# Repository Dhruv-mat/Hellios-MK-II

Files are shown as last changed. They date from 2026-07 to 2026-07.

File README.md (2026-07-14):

# Project Description

Helios Mk-II is an autonomous rover engineered to actively analyze and understand its environment rather than just driving between coordinates. The core navigation loop is straightforward: the rover is given a target GPS location and determines its own path to the destination. When encountering an obstacle, it avoids forcing a path; instead, it decelerates, scans the surroundings using its integrated LiDAR and camera payload, maps out a local environment model, and dynamically computes a safe detour or calculates an entirely new route if the path is completely blocked.

To bridge the gap between complex robotics and user experience, Helios features an AI-powered mission narration engine. Rather than outputting standard, dry terminal logs, the system synthesizes the navigation telemetry into a real-time narrative. Every sudden obstacle, recalculated path, or mission milestone is translated into a live commentary stream, transforming standard autonomous data tracking into an engaging, story-driven experience.

Beyond navigation, the rover includes a dedicated research mode designed for localized data collection. While traversing an area, the platform captures high-resolution imagery and logs environmental telemetry, geotagging all data points with precise GPS coordinates. This payload data can be extracted post-mission for specialized applications like agricultural monitoring, plant disease detection, or environmental mapping, making the vehicle a highly capable mobile sensor platform.

Future development plans include a hardware-linked follow-me mode. In this configuration, the rover tracks a dynamic target—such as a mobile device interface—instead of a fixed geographic coordinate. While following, the AI narration engine remains fully active, contextualizing the local environment and interactions in real time to turn a routine field test into an interactive demonstration.

At its core, Helios Mk-II integrates robotics, computer vision, autonomous navigation, embedded systems, and generative AI into a single cohesive platform. The objective extends beyond basic mobility; the project aims to deliver an intelligent system capable of environmental awareness, autonomous decision-making, high-utility data collection, and intuitive human-robot interaction.

# Build Guide
## Step 1: The Main Chassis & Pillars

Start by printing out the main base. Next, grab the B and C pillars. You’ll need to pop M3 nuts right into the slots on the pillars themselves, then secure them by driving M3 screws up from the bottom of the base. Go ahead and repeat this process for both sides. Once the pillars are locked down, take the B and C pillar stabilizers and slide them in from the top—they should just drop right into place. After that, use a bit of glue to secure the canopy onto the Main Base.







## Step 2: The Differential, Pillars, and Roofs

Next up is the differential plate. Insert M3 nuts into the diff connector, and secure it by screwing it in from the bottom of c pillar stabaliser plate. Use this exact same method as the pillar mounting way to attach to the rear wing. Once those are in place, you can just magnetically snap roof A and roof B onto the top.





## Step 3: The Suspension & Carbon Fiber Rods

Moving on to the B pillars, press-fit two ball bearings into each side. Once those are seated, take the main connector and fasten it onto the small pendulum piece using four screws. Now grab your carbon fiber rods, cut them down to 15 cm and 17 cm lengths, and secure them directly into the main connector.





## Step 4: The Bogie and Front Steering Setup

Mount the bogie connector to the rear, and fit the servo holder onto the front. Make sure to press two ball bearings into the bogie connector, then bolt the entire bogie assembly together using an M6 bolt.





To link up the front connector to the front motor housing, you'll first need to mount the servo motor into the front servo housing connector. Once the servo is seated, the front assembly hooks right on with a few screws. For the middle and rear sections, simply slide the motor housings into place and lock them down with screws, then press the motors inside.



## Step 5: Linking the Pendulums & Differential

For the top section, take the pendulum connector and secure it onto the pendulum using an M5 bolt to bridge both sides.

To get the differential linkage hooked up, take the diff and a ball bearing. Pop the bearing inside the diff connector, then bolt the connector onto the differential using an M5 bolt. Make sure to tighten this diff connector piece just a little bit so it has room to pivot. Next, take the LR66 linkages and screw them onto both ends of the diff. Finally, grab an M6 bolt and attach the pendulum connector directly to the LR66.



## Step 6: Final Assembly & Electronics

With everything linked up, you can go ahead and pop the wheels onto the motor shafts. To get the electronics and your custom PCB mounted inside the chassis, just follow the electronics placement guide and refer to the main wiring diagram to get all your connections sorted.





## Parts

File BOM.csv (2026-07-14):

No. | Part Name | Quantity | Owned | Seller | Price
1 | Pro-Range OG555 High Torque DC Motor 12V 100RPM 173.6N-cm Encoder Available | 6 | No | Robu | 50
2 | SmartElex 15D PWM & RC Dual Channel Motor Driver | 3 | No | Robocraze | 44
3 | Arduino Mega | 1 | No | Robocraze | 11
4 | Lidar | 1 | Yes | Robu | -
5 | Rasberry PI AI Camera | 1 | Yes | Robocraze | -
6 | Rasberry PI 5 | 1 | Yes | Robu | -
7 | PDB | 1 | Yes | Amazon | -
8 | GPS | 1 | Yes | Amazon | -
9 | GSM | 1 | Yes | Robu | -
10 | RC KIT | 1 | Yes | Robu | -
11 | M3 Screw Pack | 1 | Yes | Only Screws | -
12 | 626 ZZ - Deep Groove Ball Bearing (ID:6mm OD:19mm T:6mm) | 6 | No | Only Screws | 1.1
13 | 625 ZZ - Deep Groove Ball Bearing (ID:5mm OD:16mm T:5mm) | 3 | No | Only Screws | 0.6
14 | M3 X 5mm Brass Threaded Inserts (Dia. 3mm, Length 5mm) | 25 | No | Only Screws | 0.6
15 | Neodymium Bar Magnet N35 (Length: 25mm, Breadth: 10mm, Thickness: 2mm) | 8 | No | Only Screws | 2.3
16 | Pro-Range DS3218 20kgcm Metal Gear Digital Servo Motor - 180 degree | 2 | No | Robu | 26
17 | Carbon Fiber Tube (Hollow)16mm(OD)*14mm(ID)*185mm(L) (Twill Matte Black) | 6 | No | Robu | 9
18 | Lipo Battery | 1 | Yes | Robu | -
19 | UBEC | 1 | No | Robu | 2
20 | M6 X 65mm Hex Bolt SS304 (Dia. 6mm, Length. 65mm) | 2 | No | Only Screws | 0.7
21 | M3 X 20mm Male to Female Nylon Hex Threaded Standoff Spacer | 12 | No | Only Screws | 0.5
22 | M6 X 45mm Hex Bolt SS304 (Dia. 6mm, Length. 45mm) | 2 | No | Only Screws | 0.3
23 | M6 X 50mm Hex Bolt SS304 (Dia. 6mm, Length. 50mm) | 2 | No | Only Screws | 0.3
24 | Arduino-to-Pi cable(type b usb) | 1 | Yes | Amazon | -
25 | Robot car Wheel (125mm) Black-Blue with (6mm Coupling) | 6 | No | Robocraze | 36
26 | M5 X 16mm Hex Bolt SS304 (Dia. 5mm, Length. 16mm) | 2 | No | Only Screws | 0.07
27 | M5 Hex Nut SS304 (Dia. 5mm) | 4 | No | Only Screws | 0.02
28 | M6 Plain Washer SS304 (ID. 6.7mm OD:11.8mm T:1.6mm) | 12 | No | Only Screws | 0.19
29 | M6 Hex Nut Mild Steel Black (Dia. 6mm) | 8 | No | Only Screws | 0.09
30 | M6 X 80mm Hex Bolt SS304 (Dia. 6mm, Length. 80mm) | 2 | No | Only Screws | 0.26
31 | M5 Plain Washer SS304 (ID. 5.4mm OD:9.8mm T:1mm) | 6 | No | Only Screws | 0.19
32 | M5 X 25mm Hex Bolt SS304 (Dia. 4mm, Length. 25mm) | 2 | No | Only Screws | 0.09
33 | 20AWG 3 Core Multicore Silicone Cable Red Black Green Flexible Wire | 3 | no | Robu | 3.63
34 | 14AWG Silicone Braided wire-Black | 1 | No | Robu | 1
35 | 14AWG Silicone Braided wire-Red | 1 | No | Robu | 1
36 | PCB Manufacturing | 1 | No | JLC | 2
37 | 1x40 Pin 2.54MM Berg Strip Male connector | 2 | No | Robu | 1
38 | LED red | 1 | yes | Robu | -
39 | LED white | 1 | yes | Robu | -
40 | LED blue | 1 | yes | Robu | -
41 | resistor 470Ω | 3 | yes | Robu | -
42 | Heat Shrink | 1 | yes | Robu | -
43 | Zip Ties | 1 | yes | Robu | -
44 | XT60 male | 1 | no | Robu | 1
45 | Battery voltage checker | 1 | yes | Robu | -
46 | 2.54mm 1x40 Pin Female Single Row Header Strip | 3 | No | Robu | 1
 |  |  |  | T
 |  |  | TOTAL |  | 144$

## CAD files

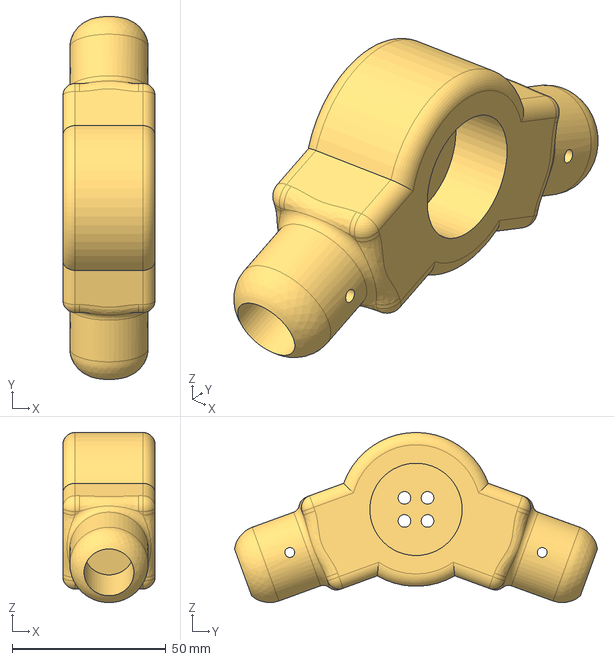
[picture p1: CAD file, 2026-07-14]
3D Files/Connectors/Connector_Main_L.step
30.0 x 118.0 x 55.3 mm

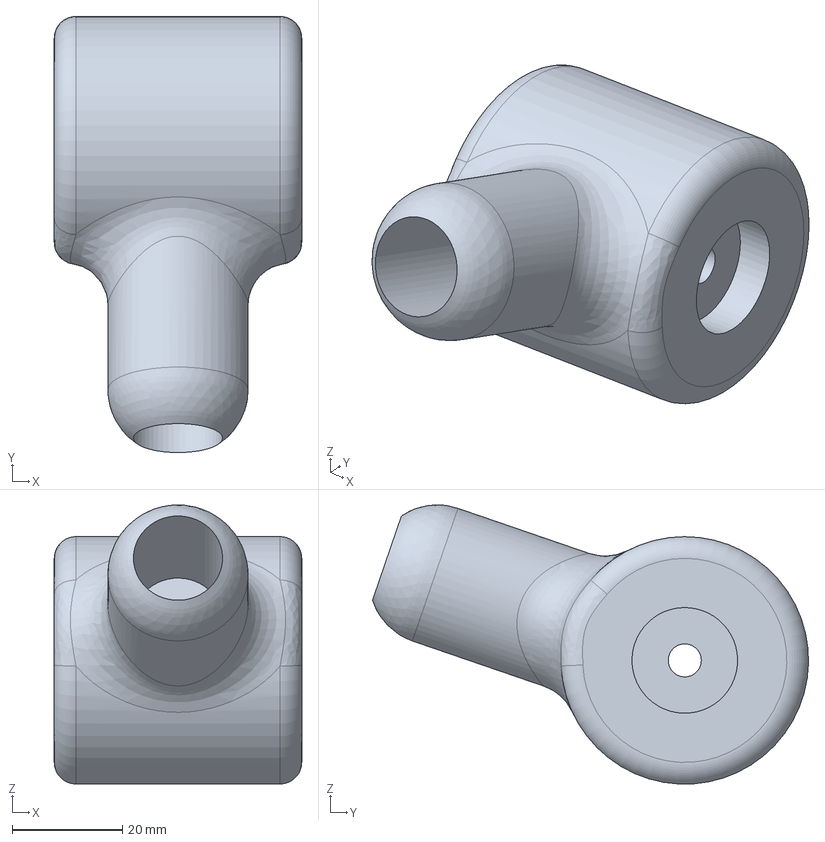
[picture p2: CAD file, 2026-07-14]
3D Files/Connectors/Bogie_Connector_L.step
45.0 x 79.3 x 50.7 mm

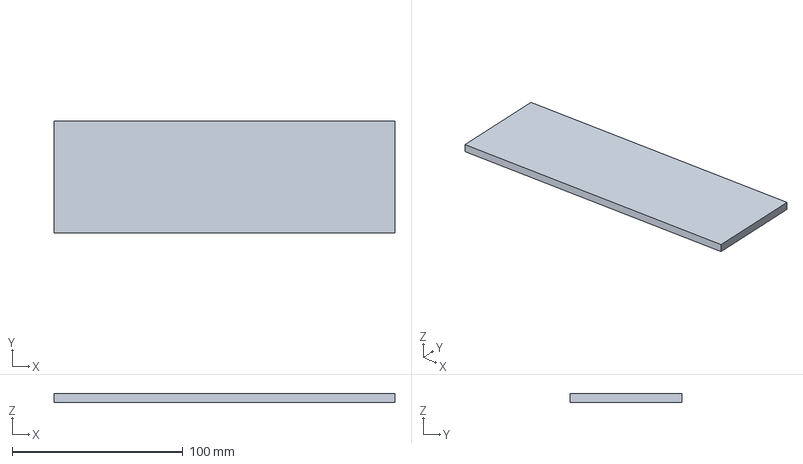
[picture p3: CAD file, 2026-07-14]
3D Files/Main Body/roof_b.step
200.0 x 66.0 x 5.00 mm

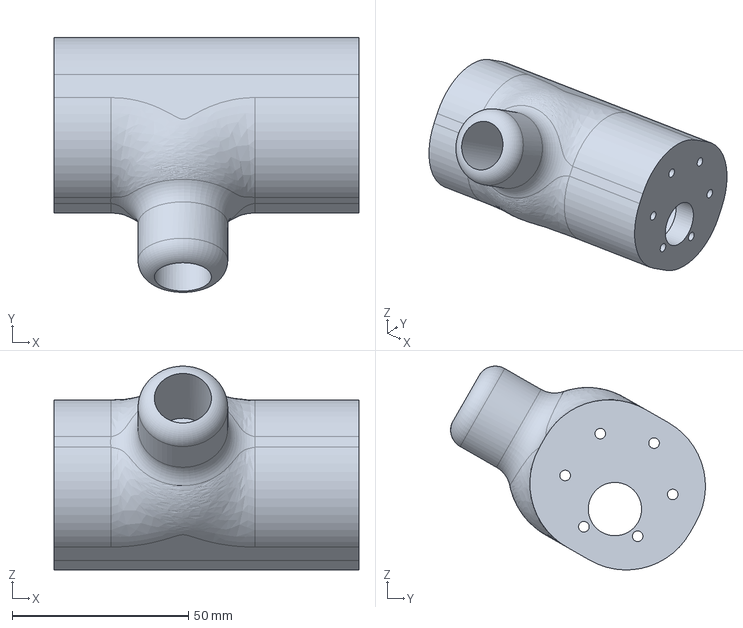
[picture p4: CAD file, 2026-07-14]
3D Files/Connectors/Motor_housing_rear_R.step
86.6 x 72.4 x 57.9 mm

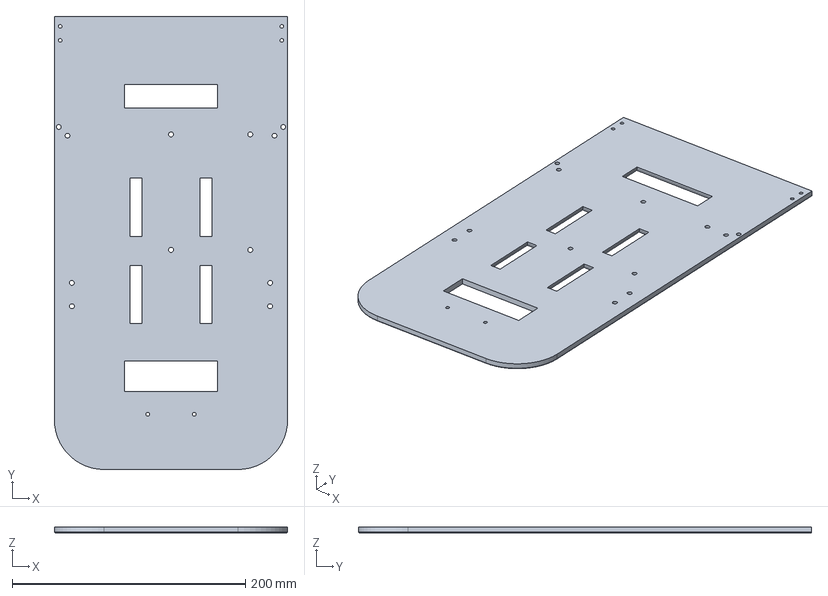
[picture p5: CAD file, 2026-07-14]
3D Files/Main Body/Base.step
200.0 x 388.5 x 5.00 mm

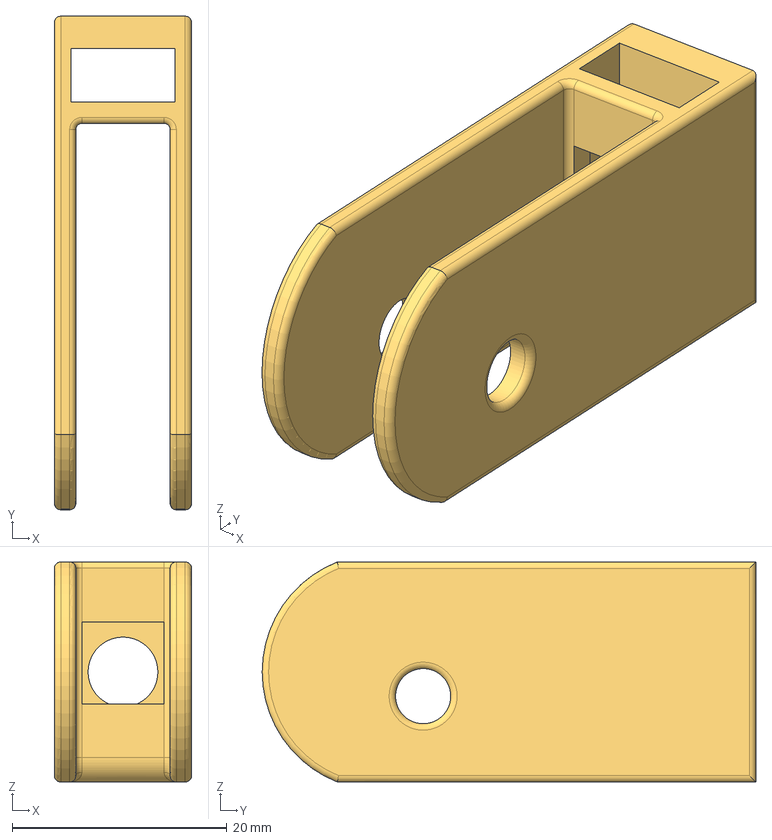
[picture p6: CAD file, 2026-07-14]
3D Files/Connectors/Pend_connector_L.step
12.8 x 46.0 x 20.5 mm

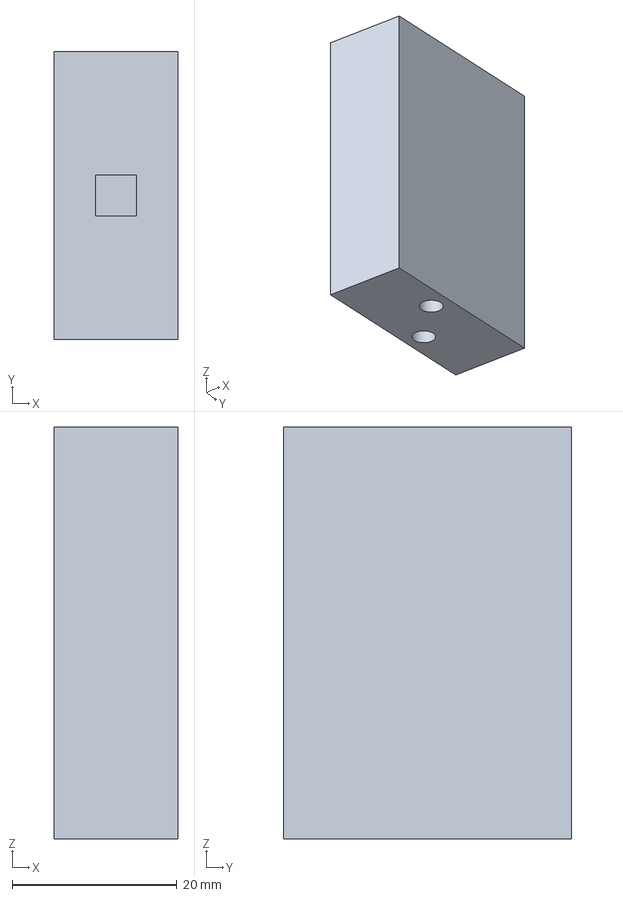
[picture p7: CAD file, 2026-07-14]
3D Files/Main Body/C_Pillar_L.step
15.0 x 35.0 x 50.0 mm

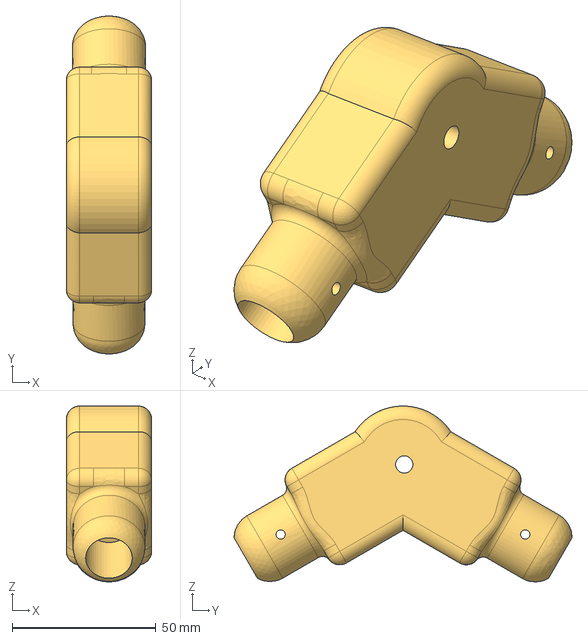
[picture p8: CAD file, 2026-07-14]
3D Files/Connectors/Bogie_R.step
29.7 x 117.4 x 61.2 mm

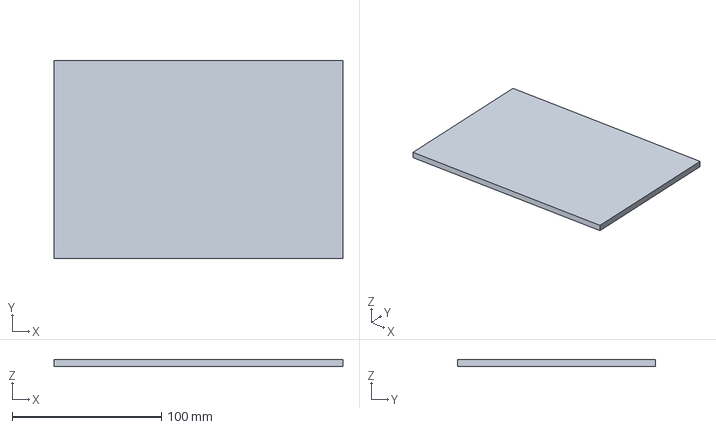
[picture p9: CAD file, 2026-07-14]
3D Files/Main Body/roof_a.step
193.6 x 132.5 x 5.00 mm

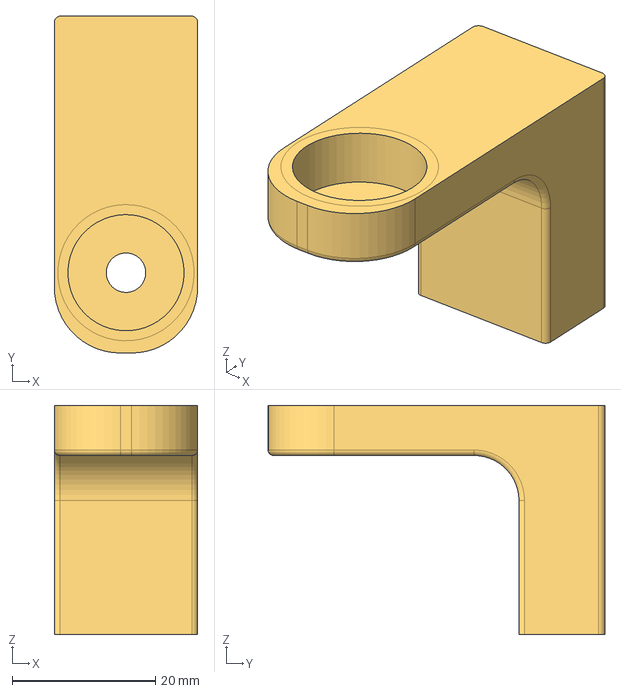
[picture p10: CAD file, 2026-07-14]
3D Files/Main Body/Diff_connector.step
20.0 x 47.0 x 32.0 mm

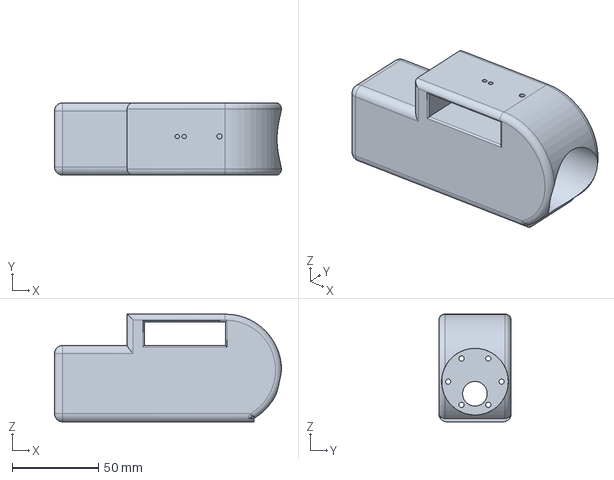
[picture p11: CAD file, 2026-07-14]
3D Files/Connectors/Motor_housing_fwd_L.step
131.7 x 42.0 x 62.5 mm

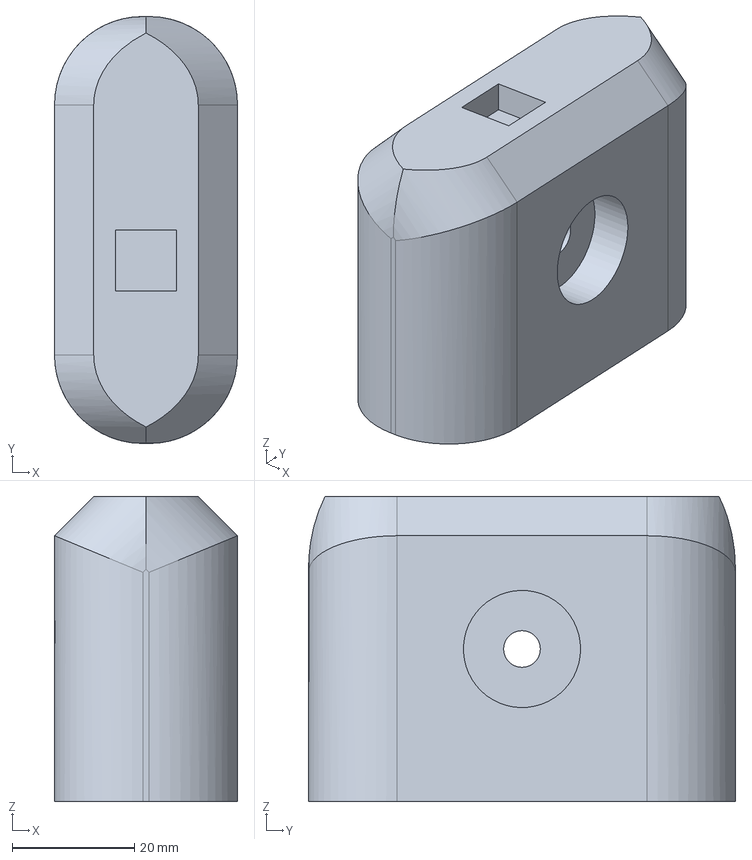
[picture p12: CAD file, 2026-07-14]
3D Files/Main Body/B_pillar_L.step
30.0 x 70.0 x 50.0 mm

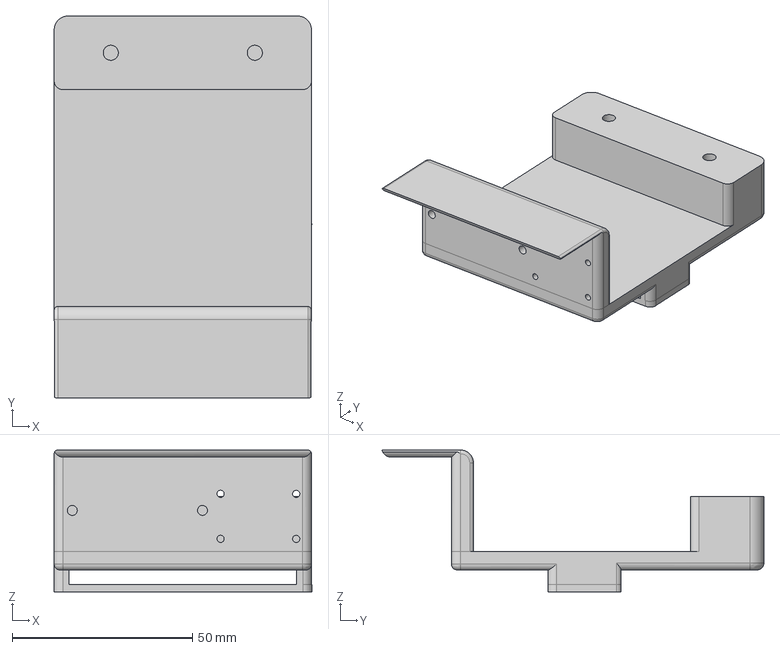
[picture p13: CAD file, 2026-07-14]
3D Files/Main Body/rover_sensor_array.step
71.6 x 106.1 x 39.4 mm

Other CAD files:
3D Files/Connectors/Connector_main_R.step
3D Files/Connectors/Pend_Connector_R.step
3D Files/Connectors/Motor_housing_rear_L.step
3D Files/Main Body/B_Pillar_R.step
3D Files/Connectors/Motor_housing_fwd_R.step
3D Files/Connectors/Bogie_L.step
3D Files/Connectors/Bogie_connector_R.step
3D Files/Connectors/Motor_housing_mid_L.step
3D Files/Connectors/Motor_housing_mid_R.step
3D Files/Connectors/Pendulum_L.step
3D Files/Connectors/Pendulum_R.step
3D Files/Connectors/Servo_holder_L.step
3D Files/Connectors/Servo_holder_R.step
3D Files/Main Body/C_Pillar_R.step
3D Files/Main Body/Canopy.step
3D Files/Main Body/Diff.step
3D Files/Main Body/Wing.step
3D Files/Main Body/pillar stabaliser_.step
3D Files/Main Body/roof_c.step

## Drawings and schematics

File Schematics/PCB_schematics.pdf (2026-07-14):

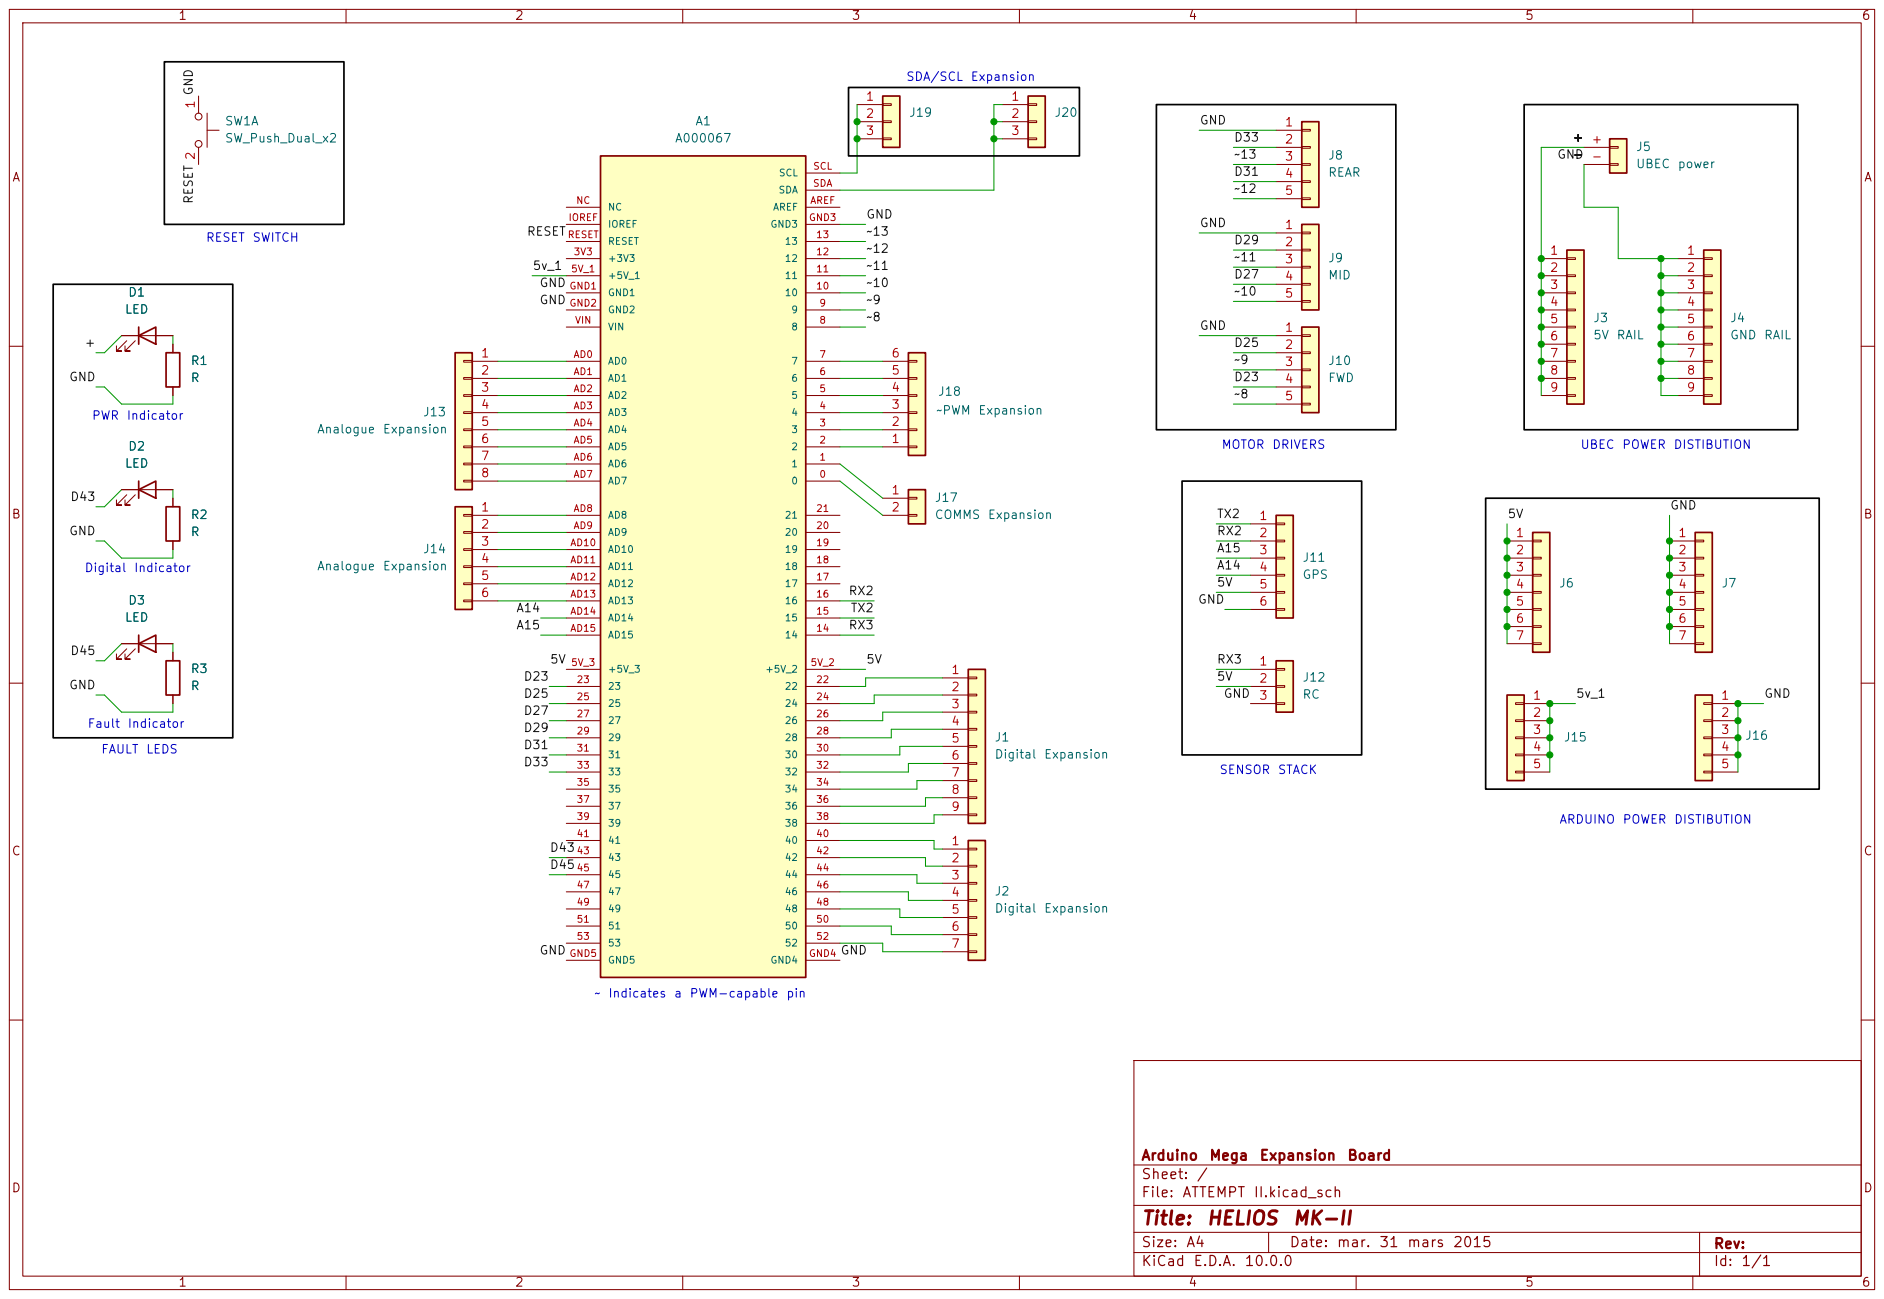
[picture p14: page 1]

4 | AD3 | 4 3
5 | AD4 | 2
6 | AD5 | 2 1

~ Indicates a PWM-capable pin

Arduino Mega Expansion Board
Sheet: /
D Date: mar. 31 mars 2015 KiCad E.D.A. 10.0.0
File: ATTEMPT II.kicad_sch
Title: HELIOS MK-II

Size: A4 | Rev:

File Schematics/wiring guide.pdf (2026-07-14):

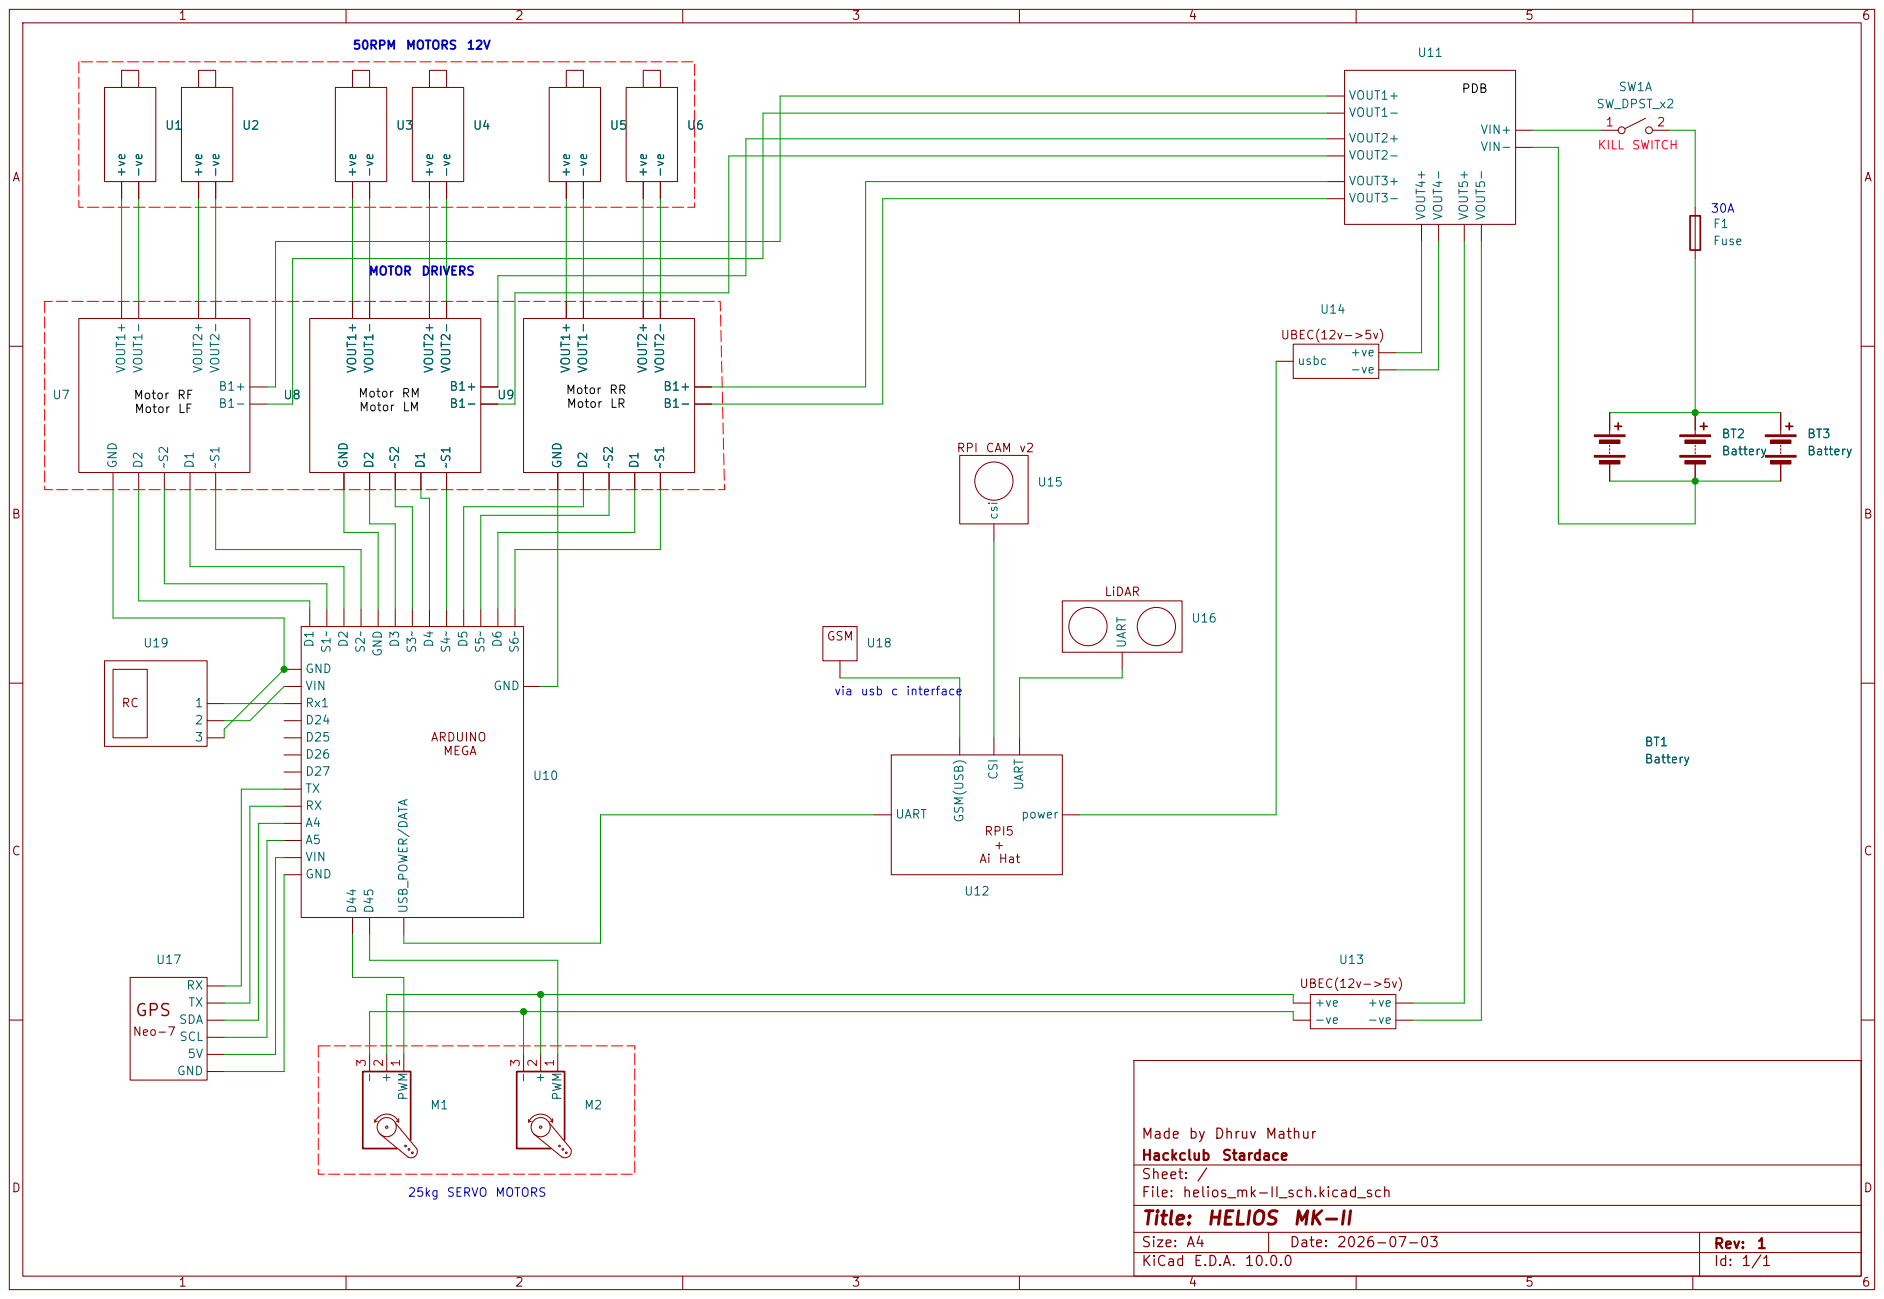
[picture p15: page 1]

30A Motor RR Motor LR Motor RM

MOTOR DRIVERS

Made by Dhruv Mathur GPS

Hackclub Stardace
Sheet: /
D Date: 2026-07-03 KiCad E.D.A. 10.0.0
File: helios_mk-II_sch.kicad_sch
Title: HELIOS MK-II

Size: A4 | Rev: 1

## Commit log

2026-07-14 3d Files added
    [B_Pillar_R.step, B_pillar_L.step, Base.step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]
2026-07-14 BOM added
    [Untitled spreadsheet - Sheet1.csv]
2026-07-14 PCB files and schematics updated
    [BOM.csv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]
2026-07-14 Add assembly instructions to README
    Added detailed assembly instructions for the project, including steps for the main chassis, differential, suspension, bogie, and final assembly with electronics.
